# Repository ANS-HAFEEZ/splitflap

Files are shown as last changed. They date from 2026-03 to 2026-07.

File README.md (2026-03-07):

# Split-Flap Display

This is a DIY ESP32-based [split-flap display](https://en.wikipedia.org/wiki/Split-flap_display), optimized for easy assembly at home in small quantities but able to be scaled up to large affordable displays.

animated rendering






The [splitflap community Discord server](https://discord.com/invite/wgehm3PcrC) is the best place to keep up with the latest changes or ask questions about the project!

Want to help support development or just say "thanks"? Consider a one-time or monthly sponsorship:

| [:heart: Sponsor scottbez1 on GitHub](https://github.com/sponsors/scottbez1) |
|---|

<a href="https://www.youtube.com/watch?v=UAQJJAQSg_g" target="_blank">
  
</a>

**Using this project in a commercial setting or for paid client work?** Go right ahead - it's open source (just make sure to follow the terms of the Apache License)! I would, however, ask that you consider [sponsoring the project](https://github.com/sponsors/scottbez1). I've been developing and maintaining this project in my free time for over 10 years, and I'd love to continue working on it. Sponsorships allow me to pay for prototypes and development tools that make this project possible. Unlike pure software projects, every iteration has real hardware costs; sponsorships allow me to keep iterating and improving the project faster. Thank you!

# Current Status
[You can download the **latest stable releases** of the hardware designs from the official 'releases' page.](https://github.com/scottbez1/splitflap/releases)

Releases have been tested and used to produce working units, but as this is a continuously evolving open-source project, there may always be minor issues and/or incomplete documentation from time to time.

Here's a video of a large 108-module display powered by 18 Chainlink Driver boards and a Chainlink Base:

Video: animations on 108-module display (https://youtu.be/g9EPabcxBsM)

## Stable v2 Mechanical Release
As of 2025-01-19, the v2 refresh of the mechanical and sensor design is considered stable and recommended for new builds.

**Here's what's new in v2:**

- **40 flaps per module is the default configuration in this repository**
- **52-flap v2 modules remain supported** if you want additional symbols/color blocks
- **New printed flap design ("Epilogue")** with 52 flaps per set (see animation above), including several color-block flaps
- **Updated enclosure** and mechanical parts (laser-cut) to accomodate both 40- and 52-flap variants
  - Motor wires now exit downward for less awkward wiring!
- **New sensor PCB** that's easier to assemble and includes an LED for checking the magnet status
- **Software-configurable calibration** rather than mechanical sensor adjustment

**But many things are staying the same for easy upgrades/compatibility:**
- No change to flap dimensions!
- No changes to Chainlink Driver, Chainlink Buddy boards, or system architecture!
- 52-flap modules are still an officially supported option!
- Open source, as always!
- v0 parts (sensor kits) will continue to be stocked at Bezek Labs through mid-2025; don't worry if you haven't finished your build yet, the old sensor kits aren't going away for a little while!

I'd love to hear your thoughts and questions about this project, and happy to incorporate any feedback you might have into these designs! Please feel free (and encouraged) to [open GitHub issues](https://github.com/scottbez1/splitflap/issues/new), email me directly, reach out [on Bluesky](https://bsky.app/profile/scottbez1.bsky.social), and [get involved](https://github.com/scottbez1/splitflap/pulls) in the open source development and let's keep chatting and building together!

# Build Your Own
If you have any questions, please don't hesitate to ask in the [community Discord server](https://discord.gg/Hxnftc8PyW)!

* [**Documentation Index**](/docs/DocumentationIndex.md)
* [**Ordering guide (the "easy" route) v2**](/docs/v2/OrderingEasy.md)
* [**Comprehensive ordering guide**](/docs/v2/OrderingComplete.md)
* [**Chainlink Driver Electronics User Guide**](/docs/ElectronicsGuide.md)
* [**Assembly instructions v2**](/docs/v2/Assembly.md)
* [**Latest stable releases**](https://github.com/scottbez1/splitflap/releases)

# Table of Contents
- [Design Overview](#design-overview)
  - [Mechanical](#mechanical)
    - [Combined front panel (script)](#combined-front-panel-script)
    - [Flap font/sticker generator (script)](#flap-fontsticker-generator-script)
  - [Electronics](#electronics)
    - [Sensor PCBs](#sensor-pcbs-1-per-module)
    - [Chainlink Driver](#chainlink-driver-1-per-6-modules)
    - [Chainlink Buddy \[T-Display\]](#chainlink-buddy-t-display-1-for-entire-display)
    - [Advanced items](#advanced-items)
      - [Chainlink Buddy \[Breadboard\]](#chainlink-buddy-breadboard-1-for-entire-display-alternative-to-t-display)
      - [Chainlink Base](#chainlink-base-1-for-entire-display-large-displays)
    - [Older designs](#older-designs)
      - [Classic controller](#classic-controller-electronics-deprecated)
    + [Miscellaneous Tools](#miscellaneous-tools)
      - [3D Printed Tools](#3d-printed-tools)
      - [Chainlink Driver Tester](#chainlink-driver-tester)
  * [Code](#code)
    + [Firmware](#firmware)
    + [Computer Control Software](#computer-control-software)
- [Contributing/Modifying](#contributingmodifying)
  * [3D Design](#3d-design)
  * [Electronics Design](#electronics-design)

# Design Overview

## Mechanical
The mechanical/structural components are made from laser-cut 3mm MDF or acrylic, and held together with M4 bolts and nuts. The design is parametric and built using OpenSCAD. See below for more info on rendering/modifying the design.

You can view an interactive 3d model of the design [here](https://scottbez1.github.io/splitflap/embed.html?branch=master).

The v2 mechanical design officially supports both 40- and 52-flap variants (52 is perfect for use with the new ["Epilogue" printed flaps](https://bezeklabs.etsy.com/listing/1685633114/)). Repository defaults are configured for 40 flaps, but you can always override this.

### v2 (52-flap module option)
2d laser cut rendering

Instructions: [v2 assembly guide](/docs/v2/Assembly.md)

Module dimensions: 

Latest auto-generated (untested!) artifacts<sup>:warning:</sup>:
* For Ponoko 3mm MDF ([svg](https://s3.amazonaws.com/splitflap-artifacts/master/3d/3d_laser_vector-52-ponoko-3mm-mdf_1x.svg)) 
* For Ponoko 3mm acrylic ([svg](https://s3.amazonaws.com/splitflap-artifacts/master/3d/3d_laser_vector-52-ponoko-3mm-acrylic_1x.svg)) 
* For generic material (0.18mm kerf correction) ([svg](https://s3.amazonaws.com/splitflap-artifacts/master/3d/3d_laser_vector-52.svg))
* For Elecrow 3mm Wood ([zipped pdf](https://s3.amazonaws.com/splitflap-artifacts/master/3d/3d_laser_vector-52-elecrow-3mm-wood_1x.zip))
* For Elecrow 3mm Acrylic ([zipped pdf](https://s3.amazonaws.com/splitflap-artifacts/master/3d/3d_laser_vector-52-elecrow-3mm-acrylic_1x.zip))

<sup>:warning:</sup>For tested/stable/recommended artifacts, always use the [latest release](https://github.com/scottbez1/splitflap/releases) instead, as the links on this page will change over time.

### v2 (40-flap module option - default)
2d laser cut rendering

Instructions: [v2 assembly guide](/docs/v2/Assembly.md)

Module dimensions: 

Latest auto-generated (untested!) artifacts<sup>:warning:</sup>:
* For Ponoko 3mm MDF ([svg](https://s3.amazonaws.com/splitflap-artifacts/master/3d/3d_laser_vector-40-ponoko-3mm-mdf_1x.svg)) 
* For Ponoko 3mm acrylic ([svg](https://s3.amazonaws.com/splitflap-artifacts/master/3d/3d_laser_vector-40-ponoko-3mm-acrylic_1x.svg)) 
* For generic material (0.18mm kerf correction) ([svg](https://s3.amazonaws.com/splitflap-artifacts/master/3d/3d_laser_vector-40.svg))
* For Elecrow 3mm Wood ([zipped pdf](https://s3.amazonaws.com/splitflap-artifacts/master/3d/3d_laser_vector-40-elecrow-3mm-wood_1x.zip))
* For Elecrow 3mm Acrylic ([zipped pdf](https://s3.amazonaws.com/splitflap-artifacts/master/3d/3d_laser_vector-40-elecrow-3mm-acrylic_1x.zip))

<sup>:warning:</sup>For tested/stable/recommended artifacts, always use the [latest release](https://github.com/scottbez1/splitflap/releases) instead, as the links on this page will change over time.

### Combined front panel (script)
By default, the design will have a separate laser-cut faceplate for each individual module. For larger displays you may want to combine front panels into a single piece, and the repo has a script to help with this.

You can modify:
* Number of rows and columns
* Horizontal and vertical spacing/separation of modules
* Overall outer width and height of the panel

There are a lot of options; see the `--help` for explanations.

#### Example 1 - Laser cut 6x1

<a href="https://s3.amazonaws.com/splitflap-artifacts/master/3d/3d_front_panel-40-elecrow-3mm-acrylic-6x1.svg">

</a>

```
python3 3d/scripts/generate_combined_front_panel.py \
  --kerf-preset elecrow-3mm-acrylic \
  --num-flaps 40 \
  --cols 6 \
  --rows 1 \
  --spacing-x 0 \
  --spacing-y 0 \
  --frame-margin-x 0 \
  --frame-margin-y 0 \
  --center-mode module
```

#### Example 2 - CNC router 12x2, with frame margin
<a href="https://s3.amazonaws.com/splitflap-artifacts/master/3d/3d_front_panel-40-3.175-20x4margin-12x2.svg">

</a>

For CNC cutting, the script supports rendering a vector file optimized for thicker material (e.g. 6mm MDF) where only the bolt-holes will be through-cut. In this mode, the slots for the top/bottom enclosure pieces can be cut as ~4mm pockets so they aren't visible from the front face. The script automatically generates dog-bone shapes for these pocket cuts.

This example also demonstrates use of the --frame-margin-x and --frame-margin-y options to add an additional margin of 20mm horizontally and 4mm vertically to the front panel dimensions.

```
python3 3d/scripts/generate_combined_front_panel.py \
  --tool-diameter 3.175 \
  --num-flaps 40 \
  --cols 12 \
  --rows 2 \
  --spacing-x 0 \
  --spacing-y 0 \
  --frame-margin-x 20 \
  --frame-margin-y 4 \
  --center-mode module
```

### Flap font/sticker generator (script)
If you'd like to print your own flaps, or cut custom vinyl letter stickers, the project includes a script (`generate_fonts.py`) to generate vector design files, which is extremely configurable:

* Font for text
  * This is further customizable in `flap_fonts.scad` -- this is where font parameters are defined like the overall font scale, position offsets, and even per-character scale and position overrides in case you need to tweak particularly problematic letters (e.g. a really wide "W" or an "@" with too thin of a stroke).
* Character-set - which letters/numbers/symbols/colors are included and in what order
* Bleed - extends rendering past the borders of the flaps to compensate for slight misalignment of printing and cutting operations
* Keepout areas - option to highlight keepout violations for manual review, automatically clip them, or ignore them
* Rendering options:
    * Single-sided - useful for previewing how all letters will look on flaps
    * Front/back - for batch duplex printing, generate separate front-side and back-side files (e.g. sign shop printing on a flat sheet of PVC)
    * Side-by-side - for individual flap printing, each flap's front design is laid out side-by-side with its back design

There are a lot of options; see the `--help` for explanations.

#### Example 1 - Epilogue font, rendered in front+back pairs, default character set, 1mm bleed (for printing)

<a href="https://s3.amazonaws.com/splitflap-artifacts/master/3d/font_example-Epilogue-1mmBleed.svg">

</a>

```
python3 3d/scripts/generate_fonts.py \
  --mode side-by-side \
  --font Epilogue \
  --columns 4 \
  --bleed 1 \
  --fill
```

## Electronics
> [!NOTE]
> For small displays (up to 3 modules), you can skip the custom controller boards and use off-the-shelf ULN2003A driver
modules plugged into an Arduino Uno. This is [partially documented in the wiki](https://github.com/scottbez1/splitflap/wiki/Electronics#basic-prototyping-alternative-electronics-approach)
> but may require some additional tinkering to get it to work. _Help wanted: if you'd like to help improve these instructions,
> please reach out in the Discord server, thanks!_

The "Chainlink" electronics system is designed to support long chains of driver boards to control medium/large displays (up to 100+ split-flap modules).
It's also designed to be easy and cheap to order pre-assembled or build yourself, especially in higher
quantities, due to its simple BOM and surface-mount components.

To build a display, you'll need 3 different electronics:
* One **Sensor PCB** for every split-flap module
* One **Chainlink Driver** board for every 6 split-flap modules. This is what interfaces with the motors and sensors of each module. Chainlink Driver boards can be chained together to construct a large display.
* An ESP32 microcontroller board. There are a few options:
    * For small/medium displays, one of the **Chainlink Buddy** boards are recommended
        * **Chainlink Buddy [T-Display]**  holds a Lilygo T-Display ESP32 module which includes a built-in LCD and 2 buttons
        * **Chainlink Buddy [Breadboard]** makes it easy to connect a Chainlink Driver to a breadboard for prototyping, though you can also easily connect a Chainlink Driver to a breadboard with a few dupont wires.
    * For large displays, the **Chainlink Base** provides a number of advanced features: central
power management/distribution and fault monitoring, UART and RS-485 connections, configuration switches, and status LEDs.

### Sensor PCBs (1 per module)
Each module needs a hall-effect sensor for start-up calibration and fault monitoring. 

#### Sensors v2

<a href="https://s3.amazonaws.com/splitflap-artifacts/master/electronics-v2/panelized_sensor_smd-front-3d.png">

</a>
<a href="https://s3.amazonaws.com/splitflap-artifacts/master/electronics-v2/panelized_sensor_smd-back-3d.png">

</a>

<a href="https://s3.amazonaws.com/splitflap-artifacts/master/electronics-v2/sensor_smd-schematic.pdf">

</a>

New sensors for the v2 laser-cut hardware - these use surface mount components and are optimized for PCB assembly at JLCPCB. These new sensors are not compatible with v0.7 and older laser-cut hardware.

Packs of 6 sensors are [available mostly-assembled in the Bezek Labs store](https://bezeklabs.etsy.com/listing/1696745674),
and come with the right-angle pin headers and magnets you'll need. Purchases support continued development of this project.

Latest auto-generated (untested!) artifacts<sup>:warning:</sup>:

* Schematic [pdf](https://s3.amazonaws.com/splitflap-artifacts/master/electronics-v2/sensor_smd-schematic.pdf)
* Interactive BOM (for manual assembly) [interactive](https://s3.amazonaws.com/splitflap-artifacts/master/electronics-v2/sensor_smd-ibom.html)
* Fabrication files (single)
  * NOTE: PCBs must be 0.8mm! (rather than the more typical 1.6mm thickness)
  * PCB gerbers [zip](https://s3.amazonaws.com/splitflap-artifacts/master/electronics-v2/sensor_smd-jlc/gerbers.zip)
  * PCB BOM (for JLCPCB assembly) [csv](https://s3.amazonaws.com/splitflap-artifacts/master/electronics-v2/sensor_smd-jlc/bom.csv)
  * PCB CPL (for JLCPCB assembly) [csv](https://s3.amazonaws.com/splitflap-artifacts/master/electronics-v2/sensor_smd-jlc/pos.csv)
* Fabrication files (panelized)
  * NOTE: PCBs must be 0.8mm! (rather than the more typical 1.6mm thickness)
  * PCB gerbers [zip](https://s3.amazonaws.com/splitflap-artifacts/master/electronics-v2/sensor_smd-panelized-jlc/gerbers.zip)
  * PCB BOM (for JLCPCB assembly) [csv](https://s3.amazonaws.com/splitflap-artifacts/master/electronics-v2/sensor_smd-panelized-jlc/bom.csv)
  * PCB CPL (for JLCPCB assembly) [csv](https://s3.amazonaws.com/splitflap-artifacts/master/electronics-v2/sensor_smd-panelized-jlc/pos.csv)
* Purchase sensor kits in the US: [Bezek Labs](https://bezeklabs.etsy.com/listing/1696745674)

<sup>:warning:</sup>For tested/stable/recommended artifacts, always use the [latest release](https://github.com/scottbez1/splitflap/releases) instead, as the links on this page will change over time.

### Chainlink Driver (1 per 6 modules)
<a href="https://s3.amazonaws.com/splitflap-artifacts/master/electronics-chainlink/chainlinkDriver-3d.png">

</a>

Key features:
* Controls 6 split-flap modules per board
* Primarily SMD and all components (except the pin headers and motor connectors) are available in JLCPCB's parts library
for easy SMD/THT assembly
* Clock and latch lines are buffered on each board with a 74HC125 to support longer chains
* 2 bits of loopback error checking per board (connecting 2 spare output bits on output shift registers to 2 spare inputs) allows the controller
to validate data integrity up and down the whole chain
* Module order goes from right-to-left since this is intended to be installed and accessed from *behind* the modules

Chainlink Driver boards are [available mostly-assembled in the Bezek Labs store](https://bezeklabs.etsy.com/listing/1123280069/splitflap-chainlink-driver-v11),
and come with the additional connectors and ribbon cables you'll need. Purchases support continued development of this project.

More information on building and using Chainlink Drivers is available in the [Chainlink Driver User Guide](/docs/ElectronicsGuide.md).

Or if you'd like to order these directly from a fab, this design is optimized for assembly at JLCPCB, and files are automatically generated
for ordering *assembled* PCBs there. Or if you wish to assemble this board yourself instead of paying for assembly, 
you can view the [interactive BOM/placement tool](https://s3.amazonaws.com/splitflap-artifacts/master/electronics-chainlink/bom/chainlinkDriver-ibom.html)

Depending on available stock at JLCPCB, you may need to manually modify the BOM file to use alternative components, or regenerate the files
yourself using `export_jlcpcb.py` and specifying one or more `LCSC_ALT_*` field names to use a pre-selected alternative part number. See
the schematic for available pre-selected alternatives (check the symbol's properties/fields).

<a href="https://s3.amazonaws.com/splitflap-artifacts/master/electronics-chainlink/chainlinkDriver-schematic.pdf">

</a>

<a href="https://s3.amazonaws.com/splitflap-artifacts/master/electronics-chainlink/chainlinkDriver-pcb-raster.png">

</a>

Latest auto-generated (untested!) artifacts<sup>:warning:</sup>:

* Schematic [pdf](https://s3.amazonaws.com/splitflap-artifacts/master/electronics-chainlink/chainlinkDriver-schematic.pdf)
* PCB overview [pdf](https://s3.amazonaws.com/splitflap-artifacts/master/electronics-chainlink/chainlinkDriver-pcb-packet.pdf)
* PCB gerbers [zip](https://s3.amazonaws.com/splitflap-artifacts/master/electronics-chainlink/chainlinkDriver-jlc/gerbers.zip)
* PCB bom (for JLCPCB assembly) [csv](https://s3.amazonaws.com/splitflap-artifacts/master/electronics-chainlink/chainlinkDriver-jlc/bom.csv)
* PCB CPL (for JLCPCB assembly) [csv](https://s3.amazonaws.com/splitflap-artifacts/master/electronics-chainlink/chainlinkDriver-jlc/pos.csv)
* PCB bom (for manual assembly) [interactive](https://s3.amazonaws.com/splitflap-artifacts/master/electronics-chainlink/bom/chainlinkDriver-ibom.html)

<sup>:warning:</sup>For tested/stable/recommended artifacts, always use the [latest release](https://github.com/scottbez1/splitflap/releases) instead, as the links on this page will change over time.

### Chainlink Buddy \[T-Display\] (1 for entire display)
<a href="https://s3.amazonaws.com/splitflap-artifacts/master/electronics-chainlink-buddy-t-display/chainlinkBuddyTDisplay-3d.png">

</a>

The Chainlink Buddy \[T-Display\] is a convenient way to connect a T-Display ESP32 board (recommended microcontroller) to a chain
of Chainlink Drivers.

Key features:
* TTGO T-Display ESP32 module as the controller, which includes USB-C, color IPS LCD display and buttons
* Extra terminals for every pin of the T-Display allow you to connect any other peripherals to the ESP32 (the connection to the Chainlink Driver requires _only 4_ of the GPIOs)
* Optional barrel jack makes it easy to use a "wall wart" AC adapter/power-supply (since the Chainlink Driver only has screw terminals for power) -- plug in a 12V supply
and then run a wire from the onboard screw terminals to the Chainlink Driver's motor power screw terminals.
* Optional 5V regulator allows for powering the ESP32 without a USB connection, using the 12V motor power supply

Chainlink Buddy \[T-Display\] boards are [available in the Bezek Labs store](https://bezeklabs.etsy.com/listing/1109357786/splitflap-chainlink-buddy-t-display),
and come with the additional connectors you'll need. Purchases support continued development of this project. 

<a href="https://s3.amazonaws.com/splitflap-artifacts/master/electronics-chainlink-buddy-t-display/chainlinkBuddyTDisplay-schematic.pdf">

</a>

<a href="https://s3.amazonaws.com/splitflap-artifacts/master/electronics-chainlink-buddy-t-display/chainlinkBuddyTDisplay-pcb-raster.png">

</a>

Latest auto-generated (untested!) artifacts<sup>:warning:</sup>:

* Schematic [pdf](https://s3.amazonaws.com/splitflap-artifacts/master/electronics-chainlink-buddy-t-display/chainlinkBuddyTDisplay-schematic.pdf)
* PCB ([gerbers](https://s3.amazonaws.com/splitflap-artifacts/master/electronics-chainlink-buddy-t-display/chainlinkBuddyTDisplay-jlc/gerbers.zip) / [pdf](https://s3.amazonaws.com/splitflap-artifacts/master/electronics-chainlink-buddy-t-display/chainlinkBuddyTDisplay-pcb-packet.pdf))
* Panelized PCB ([gerbers](https://s3.amazonaws.com/splitflap-artifacts/master/electronics-chainlink-buddy-t-display/chainlinkBuddyTDisplay-panelized-jlc/gerbers.zip) / [pdf](https://s3.amazonaws.com/splitflap-artifacts/master/electronics-chainlink-buddy-t-display/chainlinkBuddyTDisplay-panelized-pcb-packet.pdf))
* PCB bom (for manual assembly) [interactive](https://s3.amazonaws.com/splitflap-artifacts/master/electronics-chainlink-buddy-t-display/bom/chainlinkBuddyTDisplay-ibom.html)

<sup>:warning:</sup>For tested/stable/recommended artifacts, always use the [latest release](https://github.com/scottbez1/splitflap/releases) instead, as the links on this page will change over time.

### Advanced items
#### Chainlink Buddy \[Breadboard\] (1 for entire display; alternative to T-Display)
<a href="https://s3.amazonaws.com/splitflap-artifacts/master/electronics-chainlink-buddy-breadboard/chainlinkBuddyBreadboard-3d.png">

</a>

The Chainlink Buddy \[Breadboard\] makes it easy to connect a Chainlink Driver to a breadboard for prototyping. You could use 5 dupont wires and have a
messy rats nest, or you could use a single ribbon cable and this slick breakout board.

Chainlink Buddy \[Breadboard\] boards are [available in the Bezek Labs store](https://bezeklabs.etsy.com/listing/1123863267/splitflap-chainlink-buddy-breadboard),
and come with the additional connectors you'll need. Purchases support continued development of this project. 

<a href="https://s3.amazonaws.com/splitflap-artifacts/master/electronics-chainlink-buddy-breadboard/chainlinkBuddyBreadboard-schematic.pdf">

</a>

<a href="https://s3.amazonaws.com/splitflap-artifacts/master/electronics-chainlink-buddy-breadboard/chainlinkBuddyBreadboard-pcb-raster.png">

</a>

Latest auto-generated (untested!) artifacts<sup>:warning:</sup>:

* Schematic [pdf](https://s3.amazonaws.com/splitflap-artifacts/master/electronics-chainlink-buddy-breadboard/chainlinkBuddyBreadboard-schematic.pdf)
* PCB ([gerbers](https://s3.amazonaws.com/splitflap-artifacts/master/electronics-chainlink-buddy-breadboard/chainlinkBuddyBreadboard-jlc/gerbers.zip) / [pdf](https://s3.amazonaws.com/splitflap-artifacts/master/electronics-chainlink-buddy-breadboard/chainlinkBuddyBreadboard-pcb-packet.pdf))
* Panelized PCB ([gerbers](https://s3.amazonaws.com/splitflap-artifacts/master/electronics-chainlink-buddy-breadboard/chainlinkBuddyBreadboard-panelized-jlc/gerbers.zip) / [pdf](https://s3.amazonaws.com/splitflap-artifacts/master/electronics-chainlink-buddy-breadboard/chainlinkBuddyBreadboard-panelized-pcb-packet.pdf))
* PCB bom (for manual assembly) [interactive](https://s3.amazonaws.com/splitflap-artifacts/master/electronics-chainlink-buddy-breadboard/bom/chainlinkBuddyBreadboard-ibom.html)

<sup>:warning:</sup>For tested/stable/recommended artifacts, always use the [latest release](https://github.com/scottbez1/splitflap/releases) instead, as the links on this page will change over time.

#### Chainlink Base (1 for entire display; large displays)
<a href="https://s3.amazonaws.com/splitflap-artifacts/master/electronics-chainlink-base/chainlinkBase-3d.png">

</a>

For larger displays, you should take additional care to make the hardware more robust to potential faults. The Chainlink Base is an experimental (but unsupported) controller design that adds some additional functionality. This has been tested and appears to work, but is not recommended for general use.

The Chainlink Base PCB is an optional alternative to a Chainlink Buddy, designed for particularly large displays.
It hosts the ESP32 and adds additional connectivity options (terminals for UART and RS485 serial) and
power distribution (independently-monitored power channels for multiple "zones" of Driver boards).

Key features:
* TTGO T-Display ESP32 module as the controller, which includes USB-C, color IPS LCD display and buttons
* Optional master relay output for 12V PSU control (5V relay, up to ~500mA coil current)
  * Future firmware will power on the 12V PSU after a startup self-test, and power off PSU in case of any faults
* 5 channels of independently monitored 12V switches for powering groups of Chainlink Driver boards (6-10A max per channel)
  * Depending on the motors you use, each channel may be able to power about 6 Chainlink Driver boards which is 36 splitflap modules
  * Each channel includes an automotive fuse holder for additional over-current protection
  * INA219 and shunt resistor provide high fidelity voltage and current monitoring 
  * Firmware will power on each channel after a startup self-test, and power off the channel in case of any faults
  * 3.3V output for powering many Chainlink Driver boards
* Flexible controller input power
  * USB power from the T-Display works by default, though external power is recommended for larger displays
  * Regulated 5V can be connected directly to the screw terminals, or
  * if you are using an always-on 12V PSU without a master relay, you can install a buck module and power the board from 12V using the 7-28V screw terminals

<a href="https://s3.amazonaws.com/splitflap-artifacts/master/electronics-chainlink-base/chainlinkBase-schematic.pdf">

</a>

<a href="https://s3.amazonaws.com/splitflap-artifacts/master/electronics-chainlink-base/chainlinkBase-pcb-raster.png">

</a>

Latest auto-generated (untested!) artifacts<sup>:warning:</sup>:

* Schematic [pdf](https://s3.amazonaws.com/splitflap-artifacts/master/electronics-chainlink-base/chainlinkBase-schematic.pdf)
* PCB overview [pdf](https://s3.amazonaws.com/splitflap-artifacts/master/electronics-chainlink-base/chainlinkBase-pcb-packet.pdf)
* PCB gerbers [zip](https://s3.amazonaws.com/splitflap-artifacts/master/electronics-chainlink-base/chainlinkBase-jlc/gerbers.zip)
* PCB bom (for manual assembly) [interactive](https://s3.amazonaws.com/splitflap-artifacts/master/electronics-chainlink-base/bom/chainlinkBase-ibom.html)

<sup>:warning:</sup>There are currently no stable releases of this board, and none are planned. Some past variants of this board have been used, to some success, but it is not considered an
officially supported design

## Older designs
### Classic Controller Electronics (deprecated)
The Classic driver board is deprecated and unsupported.

The Classic controller board was designed to plug into an Arduino like a shield, and could control 4 stepper motors.
Up to 3 driver boards could be chained together, for up to 12 modules controlled by a single Arduino.

The driver uses 2 MIC5842 low-side shift-register drivers, with built-in transient-suppression diodes, to control the motors, and a 74HC165 shift register to read from 4 hall-effect magnetic home position sensors.
There are optional WS2812B RGB LEDs which can be used to indicate the status of each of the 4 channels.

### Miscellaneous Tools

#### 3D Printed Tools
The project also includes a number of optional 3D printed designs to make assembly easier. These include:

* [a flap scoring jig](3d/tools/scoring_jig.scad) for precisely marking the cut point when splitting CR80 cards
* [a flap punch jig](3d/tools/punch_jig.scad) for aligning the punch when making the pin cutouts on either side of a flap
* [a flap container](3d/tools/flap_container.scad) for storing and organizing stacks of completed flaps

All of these designs are parametric and customizable within OpenSCAD. To print them, open up the relevant file in OpenSCAD and use `File -> Export -> Export as STL` to render the design as an STL file for your slicer.

#### Chainlink Driver Tester
<a href="https://s3.amazonaws.com/splitflap-artifacts/master/electronics-chainlink-tester/chainlinkDriverTester-3d.png">

</a>

This is not likely to be useful unless you're planning to manufacture dozens to hundreds of Chainlink Driver boards, but the Chainlink Driver Tester is a complete testbed
for Chainlink Driver boards as they come assembled by the PCBA fabricator.

This is currently under very active development.

Key features:
* TTGO T-Display (ESP32) controller, screen, and buttons for controlling tests and reporting results
* Pogo-pins for all connectors on the Chainlink Driver board-under-test (screw terminals, sensor pin headers, and motor connectors)
* 12V switch to supply motor power to the board-under-test, with automotive fuse and INA219 voltage/current monitoring (based on the Chainlink Base channel switch design)
* Separate 3.3V supply for the board-under-test, protected with a polyfuse, should avoid browning out the Tester's MCU in case of 3.3V short-circuits
* Motor and sensor connections are broken out from the pogo-pins for a full closed-loop hardware test
* Screw terminals to chain another Chainlink Driver (not under test) to validate that chained outputs work on the board-under-test
* MCP23017 GPIO expander with 8 GPIO pins exposed via headers for future expansion inputs
* Large cutout allows a barcode scanner or camera to be aimed at the bottom of the board-under-test for tracking serial numbers.
* Buzzer option for audible pass/fail feedback

<a href="https://s3.amazonaws.com/splitflap-artifacts/master/electronics-chainlink-tester/chainlinkDriverTester-schematic.pdf">

</a>

<a href="https://s3.amazonaws.com/splitflap-artifacts/master/electronics-chainlink-tester/chainlinkDriverTester-pcb-raster.png">

</a>

Latest auto-generated (untested!) artifacts<sup>:warning:</sup>:

* Schematic [pdf](https://s3.amazonaws.com/splitflap-artifacts/master/electronics-chainlink-tester/chainlinkDriverTester-schematic.pdf)
* PCB overview [pdf](https://s3.amazonaws.com/splitflap-artifacts/master/electronics-chainlink-tester/chainlinkDriverTester-pcb-packet.pdf)
* PCB gerbers [zip](https://s3.amazonaws.com/splitflap-artifacts/master/electronics-chainlink-tester/chainlinkDriverTester-jlc/gerbers.zip)
* PCB bom (for manual assembly) [interactive](https://s3.amazonaws.com/splitflap-artifacts/master/electronics-chainlink-tester/bom/chainlinkDriverTester-ibom.html)

<sup>:warning:</sup>There are currently no stable releases of this board, and there may never be as it is a niche production tool, not an end product. If you
need this tool, you are likely actively involved in development and should understand the revision history and current status of development enough to make
an informed decision about which revision(s) to use.

## Code
### Firmware
The driver firmware is written using PlatformIO with the Arduino framework and is available at [`firmware/`](firmware/). 

The firmware implements a closed-loop controller that accepts letters as input over USB serial and drives the stepper motors using a precomputed acceleration ramp for smooth control. The firmware automatically calibrates the spool position at startup, using the hall-effect magnetic sensor, and will automatically recalibrate itself if it ever detects that the spool position has gotten out of sync. If a commanded rotation is expected to bring the spool past the "home" position, it will confirm that the sensor is triggered neither too early nor too late; otherwise it will search for the "home" position to get in sync before continuing to the desired letter.

### Serial protocol
In order for a computer to communicate with the splitflap, it appears as a USB serial device.

However, usage of Arduino’s `Serial` is strictly forbidden, and instead a `logger` abstraction is provided for sending basic text debug logs. Other data is transferred in a structured way, described below.

This allows flexibility in the format of data transferred over serial, and in fact the splitflap provides 2 different serial modes that serve different purposes.

#### Plaintext mode

By default, it starts in “plaintext” mode, which is developer-friendly and you’re probably familiar with if you’ve opened a serial monitor with the splitflap connected:
```
{"type":"init", "num_modules":6}
```

However, this isn’t great for programmatically configuring or receiving updates from the splitflap, so instead the firmware offers a programmatic interface using a binary protocol based on Google’s Protobuf standard.

#### Protobuf (binary/programmatic) mode

The protobuf-based binary serial mode is a compact and flexible way to transfer structured data from the host computer to the splitflap and vice-versa.

##### Benefits of protobuf
protobuf provides several benefits over other encoding mechanisms like JSON:

1. Well-defined schema. If you’re curious about the format of data to expect or send, you just need to check the protobuf file
2. Code generation. Instead of hand-writing JSON parsers every time the data changes, protobuf provides code generation of the encoding and decoding logic, and data-structures. Splitflap uses nanopb to generate C structs based off the schema, and all the code for encoding/decoding that data from the binary format.
3. Relatively compact/efficient wire encoding. It’s not a primary goal in this project, but the binary wire encoding is generally fairly compact, due to omitting default/unspecified fields, using variable length encodings, etc. It’s certainly much more compact than JSON which uses strings to describe every field in every message.
4. Backwards/forwards compatibility. Not super relevant to this project, but many common schema changes are backwards and forwards compatible, meaning an older client or a newer client will be able to handle them gracefully.

##### Disadvantages of protobuf

1. Not human-readable. This makes it much harder to debug, as you need something that can interpret messages. Since they’re binary, viewing anything in a terminal directly will be fruitless.
2. Not self-describing. If you come across a JSON document, you can generally tell what it means because fields have string names/labels describing their contents. Protobuf has no such thing (it uses integer field numbers, which does make renaming fields easier) so you need to have a copy of the schema (.proto file - and you’d better hope it matches the data!) in order to understand an encoded message.

This is why the splitflap defaults to plaintext mode to make basic validation/debugging easier.

##### How it works
Protobuf messages are encoded to their binary wire format and a CRC32 checksum appended. Then that entire binary string is COBS encoded into a packet, and delimited/framed by 0 (NULL) bytes when sent over serial. This provides a basic packet-based interface with integrity checks (rather than the raw, stream-based interface of a serial connection).

The splitflap automatically switches to binary protobuf mode when it receives a 0 byte.

### Computer Control Software
The display can be controlled by a computer connected to the ESP32 over USB serial. If you've built a display and want to test it out, check out the web-based demo [here](https://scottbez1.github.io/splitflap) which will connect to your display using USB - no applications/installation necessary!

The firmware supports a plaintext serial mode (enabled by default) for ease of testing, and a protobuf-based binary mode used by the software libraries for enhanced programmatic control and feedback.

You can find example Typescript and Python libraries in the [`software/chainlink`](software/chainlink) folder.

# Contributing/Modifying

Looking to make some modifications or play around with the design on your local machine? Jump right in! Note that all of the scripts and automation are developed for Ubuntu. Mac OS support is planned,
but not currently implemented (but feel free to open a PR if you want to help!).

## 3D Design

The main design file is [`3d/splitflap.scad`](3d/splitflap.scad)

You'll need a recent version of OpenSCAD (e.g. 2015-03), which may need to be installed through the PPA:
`sudo add-apt-repository ppa:openscad/releases`

In general, solid objects such as the enclosure sides or spool components are built from 2d primitives and then extruded to the appropriate thickness for 3d rendering, rather than using 3d primitives. This simplifies the design without losing expressiveness; the perpendicular laser cut beam doesn't allow for cuts that vary in the Z dimension anyway.

Note that while the design is parameterized and many values may be tweaked, there is currently no error checking for invalid parameters or combinations of parameters. Please take care to validate the design if you change any parameters. For instance, while most of the design will adjust to a changed `num_modules` value, certain values may cause some elements to intersect with other elements or protrude beyond their expected dimensions.

### Rendering
#### Laser-cut vector files
The design can be rendered to 2d for laser cutting by running [`3d/scripts/generate_2d.py [--panelize <number>]`](3d/scripts/generate_2d.py), which outputs to `3d/build/laser_parts/combined.svg`. The optional `--panelize` argument allows for rendering a panel of modules in a single SVG, for bulk laser-cutting.

Internally, the design uses a `projection_renderer` module ([`3d/projection_renderer.scad`](3d/projection_renderer.scad)), which takes a list of child elements to render, and depending on the `render_index` renders a single child at a time. It also _adds_ material to each shape to account for the kerf that will be cut away by the laser.

The [`generate_2d.py`](3d/scripts/generate_2d.py) script interacts with the `projection_renderer` module by first using it to determine the number of subcomponents to render, then runs OpenSCAD to export each component to an SVG file. It does some post-processing on the SVG output (notably adds "mm" to the document dimensions), and then combines all components into the single `combined.svg` output.

Once the `combined.svg` file is generated, you'll want to double-check there aren't any redundant cut lines that are shared by multiple adjacent pieces, to save time/cost when cutting. They should be detected automatically (and highlighted in red in the rendering above), but it doesn't hurt to double-check. In Inkscape, select the "Edit paths by nodes" tool and select an edge to delete - the endpoints should turn blue. Then click "Delete segment between two non-endpoint nodes", and repeat this for all other redundant cut lines.

#### Animated gif
The design can be rendered to a rotating 3d animated gif (seen above) by running [`3d/scripts/generate_gif.py`](3d/scripts/generate_gif.py), which outputs to `3d/build/animation/animation.gif`

The `generate_gif.py` script runs multiple OpenSCAD instances in parallel to render the design from 360 degrees to individual png frames, which are then combined into the final gif animation. As part of building the animation, `generate_gif.py` renders the design with multiple configurations (opaque enclosure, see-through enclosure, no-enclosure and no flaps) by setting the `render_enclosure` and `render_flaps` variables.

#### STL models/web viewer
The design can be rendered to a series of STL files (one per color used in the model) in order to be displayed in an [interactive web-based 3d viewer](https://scottbez1.github.io/splitflap/). Similar to the `projection_renderer` used to render individual components for laser-cutting, the [ColoredStlExporter](3d/scripts/colored_stl_exporter.py) detects all the colors used in the model and renders them one-by-one to separate STL files, along with a manifest that maps each STL file to its RGB color. The STL files and manifest are loaded using three.js to display an interactive model on a web site using WebGL. See this blog post for more details on how the export and three.js renderer work: [OpenSCAD Rendering Tricks, Part 3: Web viewer](http://scottbezek.blogspot.com/2016/08/openscad-rendering-tricks-part-3-web.html).

## Electronics Design
All of the electronics are developed using KiCad 5. Panelization is provided by [KiKit](https://github.com/yaqwsx/KiKit) and gerber/BOM generation is provided by [KiBot](https://github.com/INTI-CMNB/KiBot).

### Rendering
The mechanical and electrical design renderings and links above are automatically updated on every commit with the latest rendering. See this blog post for more details on how that works: [Automated KiCad, OpenSCAD rendering using Travis CI](http://scottbezek.blogspot.com/2016/04/automated-kicad-openscad-rendering.html).

The PCB layout can be rendered to an svg or png (seen above) by running [`electronics/scripts/generate_svg.py file.kicad_pcb`](electronics/scripts/generate_svg.py).
This uses KiCad's [Python scripting API](https://docs.kicad-pcb.org/doxygen/md_Documentation_development_pcbnew-plugins.html)
to render several layers to individual svg files, manipulates them to apply color and opacity settings, and then merges them to a single svg.
For additional details, see this blog post: [Scripting KiCad Pcbnew exports](http://scottbezek.blogspot.com/2016/04/scripting-kicad-pcbnew-exports.html).

For reviewing the design, a pdf packet with copper, silkscreen, and drill info can be produced by running [`electronics/scripts/generate_pdf.py file.kicad_pcb`](electronics/scripts/generate_pdf.py).

Gerber files for fabrication can be exported by running [`electronics/scripts/generate_gerber.py file.kicad_pcb`](electronics/scripts/generate_gerber.py).
This generates gerber files and an Excellon drill file with Seeed Studio's [naming conventions](http://support.seeedstudio.com/knowledgebase/articles/1176532-how-to-generate-the-gerber-manufacturing-files) and produces a `.zip` which can be sent for fabrication.

EESchema isn't easily scriptable, so to export the schematic [`electronics/scripts/export_schematic.py`](electronics/scripts/export_schematic.py) starts an X Virtual Frame Buffer (Xvfb) and open the `eeschema` GUI within that virtual display, and then send a series of hardcoded key presses via `xdotool` to interact with the GUI and click through the dialogs. This is very fragile but seems to work ok for now. For additional details, see this blog post: [Using UI automation to export KiCad schematics](http://scottbezek.blogspot.com/2016/04/automated-kicad-schematic-export.html).

# License
I'd love to hear your thoughts and questions about this project, and happy to incorporate any feedback you might have into these designs! Please feel free (and encouraged) to [open GitHub issues](https://github.com/scottbez1/splitflap/issues/new), email me directly, reach out [on Twitter](https://twitter.com/scottbez1), and [get involved](https://github.com/scottbez1/splitflap/pulls) in the open source development and let's keep chatting and building together!

This project is licensed under Apache v2 (see [LICENSE.txt](LICENSE.txt)).

    Copyright 2015-2025 Scott Bezek and the splitflap contributors
    
    Licensed under the Apache License, Version 2.0 (the "License");
    you may not use this file except in compliance with the License.
    You may obtain a copy of the License at
    
        http://www.apache.org/licenses/LICENSE-2.0
    
    Unless required by applicable law or agreed to in writing, software
    distributed under the License is distributed on an "AS IS" BASIS,
    WITHOUT WARRANTIES OR CONDITIONS OF ANY KIND, either express or implied.
    See the License for the specific language governing permissions and
    limitations under the License.

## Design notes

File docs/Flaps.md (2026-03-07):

[<< Back to Documentation Index](../DocumentationIndex.md)

# About flaps
Flap dimensions

The flaps in this design are based around standard credit-card sized PVC cards (aka CR80). Each flap is 1/2 of a card, and has notches cut of the sides to create a "pin" that fits into the flap spool and allows it to flip freely.

Most builds use 40 flaps per module by default in this repository, but 52-flap v2 builds are also supported. For a small 6-character display that will be a total of 240 flaps (40-flap build) or 312 flaps (52-flap build) that need to be cut and have letters applied to them if you take the full DIY approach.

Because there are so many flaps required for larger displays, I've also had custom flaps (both blank and pre-printed) manufactured that I sell in the [Bezek Labs Etsy store](https://bezeklabs.etsy.com/), which can save a lot of time and helps support continued development of this project.

# Option 1: Pre-printed flaps
Bezek Labs professionally cut blank white flaps

If you'd like to save the most time, I sell [packs of profesionally cut and printed flaps](https://www.etsy.com/listing/1685633114), ready to install into your split-flap display. THese are designed for v2 displays.

This is definitely the priciest option since they're completely custom for this project (the pre-printed Epilogue set requires 52 different printed designs), but they look great and will hold up well to long-term use.

Available in <a href="https://www.etsy.com/listing/1685633114">1-packs, 6-packs, and 24-packs in the Bezek Labs Etsy store</a>.

<a href="https://www.etsy.com/listing/1685633114">

</a>

[^ Up to top](#about-flaps)

[<< Back to Documentation Index](../DocumentationIndex.md)

# Option 2: Pre-cut blank flaps
Bezek Labs professionally cut blank white flaps
Bezek Labs professionally cut blank black flaps

An intermediate option is to buy pre-cut blank flaps, and then apply letter stickers of your choice to them. This saves the hassle of cutting/punching every flap, but still involves some tedious work to apply stickers to every flap.

I sell packs of blank flaps in the <a href="https://bezeklabs.etsy.com/listing/979720975">Bezek Labs Etsy store</a>, available in glossy white or matte black.

<a href="https://bezeklabs.etsy.com/listing/979720975">

</a>

You'll need to [apply letter stickers](#33-apply-letter-stickers) to the blank flaps.

[^ Up to top](#about-flaps)

[<< Back to Documentation Index](../DocumentationIndex.md)

# Option 3: DIY flaps
flap with notches cut by hand

If you want the full DIY experience, the flaps can be created by first cutting a CR80 card in half, then punching notches out of each side of the half cards, and finally applying letter stickers to them.

If this sounds tedious, I'll admit that it is, but it's how I built the first few splitflap modules.

## 3.1 Build a flap cutting jig

The notch cut-outs need to be done consistently for all 40 flaps, so we'll first create a jig for the [badge slot punch](http://www.amazon.com/gp/product/B009YDRRB4) to hold a flap in a precise position while cutting it.

The jig can either be created by hand using a PVC card, or, if you have a 3d printer, can simply be printed ([see below](#3d-printing-a-jig))

### 3d printing a jig

If you have a 3d printer, you can print a jig model rather than creating the jig by hand. It will look like this:

3d-printed jig

To print this jig, open [3d/punch_jig.scad](https://github.com/scottbez1/splitflap/blob/master/3d/tools/punch_jig.scad), render it and export to an STL file. You can use your slicer of choice to prepare the model for 3d printing.

3d-rinted jig Model of the 3d printed jig

(Thanks to [@SilentM4X](https://twitter.com/SilentM4X) for the [idea to print the jig](https://twitter.com/SilentM4X/status/974688413373870085)!)

### Creating a jig by hand

The jig created from a PVC card will eventually look like this:

badge punch with alignment jig

To build this, start by taking half a PVC card (or any spare ID or credit card you may have laying around), insert it all the way to the back of the punch, and punch a slot in the center. While the punch is still engaged (holding the card in place), take your X-Acto knife and lightly score the top of the card along the outer edges of the punch (just enough to mark it).

punched card with marked edges

Take the card and a ruler and score it along the 2 lines you marked (cut about 1/3 of the way through the card thickness, but err on the side of cutting less). Then align the ruler with the flat edge of the punched slot nearest the card edge and use the knife to fully cut the card from the right side of the punched slot to the right edge of the card. Then turn the ruler 90 degrees and place it ~1-2mm outside the left side of the punched slot (this determines the thickness of the flap "pin") and cut from the bottom edge of the slot to the top of the card. 

punched card with scores and cuts

Connect those 2 cuts so that the upper right section of the card can be removed entirely:

punched card with section moved

Fold the card 90 degrees away from you along the 2 scored edges:

folded jig

Insert the jig into the punch (the same orientation you originally punched it), and tape it into place:

folded jig in punch folded jig in punch 2

folded jig in punch 3 folded jig in punch 4

Your flap-cutting jig is complete!

[^ Up to top](#about-flaps)

[<< Back to Documentation Index](../DocumentationIndex.md)

## 3.2 Cut flaps

To cut the flaps from CR80 PVC cards, they first need to be cut in half. You could probably do this with a paper guillotine, but I don't own one so I made a jig to score them with a utility knife and then snap them in half.

Start by putting 3 nails into a scrap piece of wood to hold the card in place:

nails to align card

Then, on either side of the working area, place a card or two (I used a PVC card plus a business card) to elevate a ruler which will be clamped in place as a straight edge for scoring.

ruler placement

Make sure the ruler is clamped exactly 1/2 card length away from the two top nails:

ruler alignment

Then slide a blank card under the ruler and hold it tightly against the nails while scoring along the ruler edge.

card to be cut

You should get a nice clean line, which doesn't have to be too deep. 

card with score line

Bend the card away from the cut until it's folded back on itself, making sure that the ends of the card match up with each other (otherwise adjust the ruler alignment to correct for this). Then straighten the card and bend the opposite direction until it snaps in half.

folded card
folded card 2

Do this with 20 cards to get 40 half-cards. Then take each half-card and use the [[flap cutting jig|Build flap cutting jig]] to punch a notch out of each side.

punched card
stack of punched cards

 The punched holes may not be completely clean (e.g. some material left outside the hole) but that's ok. Take some diagonal cutters to clip off the excess material and clean up the top/bottom of the punched notch.

clipping card with diagonal cutters final cut flaps

If you're interested in more precise dimensions for the flaps and cutouts and the reasoning behind those values, see the discussion here: https://github.com/scottbez1/splitflap/issues/8

If you'd like to save yourself some time, an alternative to cutting your own flaps is to purchase pre-cut flaps that I've had professionally made, [available on Etsy](https://bezeklabs.etsy.com/listing/979720975). Purchasing pre-cut flaps from me will also help fund the continued development of this open-source project.

[^ Up to top](#about-flaps)

[<< Back to Documentation Index](../DocumentationIndex.md)

## 3.3 Apply letter stickers

For applying letter stickers to the flaps, I generally recommend purchasing store-bought vinyl letter sticker packs (see the [v2 complete ordering guide](/docs/v2/OrderingComplete.md) or [v0 complete ordering guide](/docs/v0/OrderingComplete.md) for details).

If you have a vinyl cutter like a Cricut or Silhouette, you can use the [generate_fonts.py](https://github.com/scottbez1/splitflap/blob/master/3d/scripts/generate_fonts.py) script to generate a custom flap letter stickers in the font/design of your choice. I recommend following [Dave Madison's excellent blog post](https://www.partsnotincluded.com/building-diy-split-flap-displays/#:~:text=Letter%20Generation) for tips on how to do this! (And kudos to Dave Madison for contributing that font generation script to the project!)

Applying the letter stickers to each of the 40 flaps is a painstaking, slow process. After a bit of practice, it still took me about 1.5 hours and a lot of patience to apply all the stickers to a new set of flaps:

video time-lapse (https://www.youtube.com/watch?v=N_ifOY9FLs8)

**Note:** I've since discovered a better way of applying letter stickers - see [New Instructions](#new-instructions). The [Old Instructions](#old-instructions) are still included below, but no longer recommended.

### New Instructions

Watch the [youtube video](https://www.youtube.com/watch?v=3lFECISLwyI):



This method is a lot less stressful and offers much better alignment than the older method.

1. Tape down old credit cards or hotel keycards so they form a U-shaped jig that cradles 2 flaps. Place 2 blank flaps into that jig. (Optionally tape another card or piece of paper that covers the bottom 3/16 inch (4.76mm) of the bottom flap -- this serves as a baseline for aligning the stickers)
1. Using food storage cling wrap applied tightly over a clear container, place the letter sticker **upside down** (sticky side UP) on the cling wrap. It should be attracted to the cling wrap because of static electricity, which will allow us to flip the whole thing over without the sticker falling off.
1. Flip the container+cling wrap+sticker over, and looking through the clear container and cling wrap, align the letter onto the 2 flaps (using the optional baseline alignment guide mentioned above, if you have it). Press the container down so the sticker adheres to the flaps and remove the container.
1. Using your finger, press down all over the letter sticker to ensure it's adhered and there are no air bubbles.
1. Cut the letter sticker in half along the gap between the 2 flaps.
1. Remove the bottom flap from the jig and set aside. Take the top flap and flip down so it's in the place of the bottom flap, and place a new blank flap in the top position.
1. Repeat steps 2-6 with the next letter sticker.

### Old Instructions

I've found it's easiest to keep the order correct by starting with all but two of the (empty) flaps already on the spool. You can add/remove flaps on the spool by gently squeezing the flap so the middle of the flap bows away from the spool's center: hold your index finger in a cup shape underneath the flap so only the flap's edges touch your finger, and then press your thumb into the center so the flap bends to follow the contour of your index finger. This will cause the pins to move inward enough to slide the flap into or out of place:

Gently bend the flap to add/remove it from the spool

Start with just 2 empty flaps off the spool, flat on your workspace arranged as they would be on the spool (vertically mirroring each other, with the pins in the middle).

For each letter:

1. Use a hobby knife to cut the letter sticker in half. I used a spare PVC card cut to 1.5 inches tall as a guide since it's smaller and easier to move around than a ruler.
1. Peel up half the letter (you can use the knife's blade to help separate the sticker from the backing), and carefully apply it to one of the flaps, with the cut edge along the flap's cut edge.
1. Repeat with the other half of the letter, making sure to align it with the half you already placed.
1. Take the bottom flap and place it back on the spool, in the lower of the two available slots.
1. Take the top flap (still sitting on your workspace) and flip it vertically so it's face-down in the bottom-flap orientation.
1. From the spool, remove the empty flap above the empty slot (above ), and place it on your workspace in the top-flap orientation.
1. Repeat the steps for each letter. You will always be placing the bottom half of the next letter on the back of the flap that has the top half of the previous letter (e.g. the bottom half of "C" is on the back of the flap with the top half of "B", and the bottom half of "9" is on the same physical flap as the top half of "8").

[^ Up to top](#about-flaps)

[<< Back to Documentation Index](../DocumentationIndex.md)

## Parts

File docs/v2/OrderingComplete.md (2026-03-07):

# Splitflap v2 Comprehensive Ordering Guide
[<< Back to Documentation Index](../DocumentationIndex.md)

The instructions below will walk you through ordering all the parts (excluding common tools) needed to build a splitflap v2 display with **6 modules** using the latest Chainlink electronics.

Ready to assemble? Jump ahead to the [Assembly Guide](Assembly.md) 

If you have any questions, please feel free to reach out to me (scott@bezeklabs.com). Or, join the [Discord server](https://discord.gg/wgehm3PcrC), to discuss or ask questions from the wider split-flap community!

😩 Feeling overwhelmed by this document? I don’t blame you, there’s a LOT here… So I put together a much shorter document that favors simplicity over comprehensiveness/lowest-cost,
for people in the US: [+Splitflap Ordering (the “easy” route)](OrderingEasy.md) 

1. [Order laser-cut parts](#order-laser-cut-parts)
3. [Order electronics](#order-electronics)
2. [Order hardware](#order-misc-hardware)

----------
# Order laser-cut parts

There are many places you can get laser-cut parts, but I’ve personally used Ponoko and Elecrow for ordering shipped to the US with an easy online-only process. I’ve previously recommended ordering from Ponoko - and while I still believe they have great quality and customer service so you'll get a great product, they’ve gotten too expensive to be my default recommendation any longer 😞 

For advanced makers: if you want to cut a single front panel that will be shared by an entire row (or grid) of modules, there is a script to do so with lots of configurable options like spacing, rows/cols, and even has a mode for generating geometry for CNC routing with necessary “dog-bones” applied to inside corners — see `generate_combined_front_panel.py`

💡 Note: v2 laser-cut parts are not dimensionally compatible with older v0 modules! If you’re extending an older display, make sure to use the older files (see the v0 [ordering instruction](../v0/OrderingComplete.md))

## Elecrow (recommended)

- Download the appropriate file (40-flap is the default in this repository):
  - 52-flap design (optional)
    - 3mm acrylic
      - Download [zip](https://s3.amazonaws.com/splitflap-artifacts/refs/tags/releases/mechanics/v2/3d/3d_laser_vector-52-elecrow-3mm-acrylic_1x.zip)
      - Go to [Elecrow acrylic laser cutting](https://www.elecrow.com/acrylic-cutting.html) and upload the zip file
      - Enter dimensions: 
      - Select thickness: 3mm
      - Engrave: No
      - Acrylic color: Matte Black (P502) is recommended
    - 3mm wood
      - Download [zip](https://s3.amazonaws.com/splitflap-artifacts/refs/tags/releases/mechanics/v2/3d/3d_laser_vector-52-elecrow-3mm-wood_1x.zip)
      - Go to [Elecrow wood laser cutting](https://www.elecrow.com/5pcs-wood-laser-cutting-service.html)
      - Dimension: 20cm Max * 20cm Max(Thickness: 3mm)
  - 40-flap design (default)
    - 3mm acrylic
      - Download [zip](https://s3.amazonaws.com/splitflap-artifacts/refs/tags/releases/mechanics/v2/3d/3d_laser_vector-40-elecrow-3mm-acrylic_1x.zip)
      - Go to [Elecrow acrylic laser cutting](https://www.elecrow.com/acrylic-cutting.html) and upload the zip file
      - Enter dimensions: 
      - Select thickness: 3mm
      - Engrave: No
      - Acrylic color: Matte Black (P502) is recommended
    - 3mm wood
      - Download [zip](https://s3.amazonaws.com/splitflap-artifacts/refs/tags/releases/mechanics/v2/3d/3d_laser_vector-40-elecrow-3mm-wood_1x.zip)
      - Go to [Elecrow wood laser cutting](https://www.elecrow.com/5pcs-wood-laser-cutting-service.html)
      - Dimension: 20cm Max * 20cm Max(Thickness: 3mm)




## Ponoko (also recommended, but pricey)
- Download the appropriate file (40-flap is the default in this repository)
    - 52-flap design (optional)
        - 3mm Acrylic: [svg](https://s3.amazonaws.com/splitflap-artifacts/refs/tags/releases/mechanics/v2/3d/3d_laser_vector-52-ponoko-3mm-acrylic_1x.svg) 
        - 3mm MDF: [svg](https://s3.amazonaws.com/splitflap-artifacts/refs/tags/releases/mechanics/v2/3d/3d_laser_vector-52-ponoko-3mm-mdf_1x.svg) 
    - 40-flap design (default)
        - 3mm Acrylic: [svg](https://s3.amazonaws.com/splitflap-artifacts/refs/tags/releases/mechanics/v2/3d/3d_laser_vector-40-ponoko-3mm-acrylic_1x.svg) 
        - 3mm MDF: [svg](https://s3.amazonaws.com/splitflap-artifacts/refs/tags/releases/mechanics/v2/3d/3d_laser_vector-40-ponoko-3mm-mdf_1x.svg) 

- Go to [Ponoko](https://www.ponoko.com/) and sign up for an account.
- [Upload](https://www.ponoko.com/designs) the SVG file from above. Confirm the dimensions match the values above, and check that blue lines are set for “Cutting” and black fill is set for “Area Engraving” (or turn this off to skip engraved features)


- Select a material - [MDF](https://www.ponoko.com/materials/mdf-fiberboard) or [Acrylic](https://www.ponoko.com/materials/black-matte-acrylic) are recommended — choose 3.0mm (0.12 inches) thickness. Make sure to check the material’s maximum size against the dimensions provided next to the file links above; some materials may be too small to order the 4x versions.

💡 **Important note if ordering Matte 1-Side acrylic at Ponoko:** you ***must*** immediately send special instructions to Ponoko after placing your order, requesting to have the design engraved on the *glossy* side. This will result in the design being correctly cut so the matte surface will be on the exterior of the display when assembled. From Ponoko support (as of 2021-05-13): 

> The matte is [by default] cut with the matte side up (so engraving happens on this side as well).
> 
> If you would like to place an order and have us engrave on the glossy side, just **reply to the order confirmation page** with your request and we'll be sure to make note in the order details.

----------
# Order electronics

The Chainlink system is a newer electronics system based around the more powerful ESP32 microcontroller (which adds things like wifi support) and incorporates learnings from the earlier Classic Controller. New development is focused on the Chainlink system.

The basic pieces that you’ll need for a Chainlink system:

- **Chainlink Driver board** (1 for every 6 split-flap modules you want to control)
- **Chainlink Buddy** + **ESP32** (1 for the whole display, regardless of size)
- **Sensors** (1 for every split-flap module)

The easiest and best-supported approach is to purchase each of those items from the Bezek Labs Etsy store (US only) - I’ve set up the store so that items comes with the necessary accessories, meaning there are fewer things you need to track down and purchase separately from different suppliers. Proceeds also help fund continued development of the project!

💡 See the [Chainlink User Guide](../ElectronicsGuide.md) for more info about different configurations.

## Order Chainlink Driver


The Chainlink Driver is what drives up to 6 split-flap modules. Multiple Chainlink Drivers can be chained (hence the name!) to create much larger displays (I have created a 108-module display using 18 Chainlink Driver boards).

The Chainlink Driver uses mostly surface-mount components so it’s optimized for factory production moreso than hand-soldering (though you can of course do that if you’d like)

[**Recommended] Option 1: Purchase fully-tested PCBA on Etsy (US shipping only)**
I sell mostly-pre-assembled [Chainlink Driver boards in the Bezek Labs Etsy store](https://bezeklabs.etsy.com/listing/1123280069/splitflap-chainlink-driver-v11) (includes accessories: connectors, ribbon cable)

These have all the tricky surface-mount components already soldered for you. You’ll just need to solder the through-hole connectors, which are pretty easy.

Every single board that I sell goes through a rigorous 100% functionality test which validates every single motor output, sensor input, LED, and data line works as expected, using a custom test jig I developed.

This option also includes all the connectors and ribbon cable you’ll need, so you don’t need to order anything separately!

And, if you want to make sure you get the right 28byj-48 motors instead of just ordering on AliExpress and hoping for the best, I’ve added an option on Etsy to include 6x motors with your Chainlink Driver order! Yes, they’re more expensive than ordering on AliExpress directly, but they’ll ship quickly and you’ll know you’re getting good motors.

**Option 2: Purchase assembled Chainlink Driver from JLCPCB, and purchase connectors and ribbon cable separately**
The Chainlink Driver design is optimized for JLCPCB assembly, so it’s mostly a drag-and-drop process, but you’ll need to carefully understand the options you select. Most importantly, if JLCPCB is out of stock of a component, *they will continue to build your order and simply omit that component!* So be careful to check all warnings or notices that appear when ordering.

Note that JLCPCB assembly involves a number of fixed costs (such as $3 per unique part, and shipping fees) which make larger quantities a better value. 

Download the following 3 items from the latest Chainlink Driver release (v1.1):

- gerber files (for the PCB)
- BOM (specifies which components are needed for assembly)
- CPL (specifies placement locations for components)

To order:



- Go to JLCPCB https://cart.jlcpcb.com/quote
- Upload gerber zip
- Select your quantity, PCB color
- Confirm other parameters:
    - Dimensions: (accept auto-generated dimensions, which will likely be 30.48 x 198.12)
    - PCB Thickness: 1.6
    - Outer Copper Weight: 1oz



- Select SMT Assembly
    - Assemble top side
    - Select your quantity to assemble
    - Tooling holes: select **Added by Customer** (these are included in the design already, so you do not need JLC to add them)
    - Confirm



- Upload BOM File
- Upload CPL (csv) file



- Review parts
    - ⚠️ Make sure you check this step carefully, as any parts that are out of stock will simply be omitted! ⚠️ 
    - “No part selected” is *normal* for several connectors that will not be assembled by JLCPCB (see below) - these will be “J”-prefixed designators such as “Motor A”, “Sensor C”, or “Input” or “Output”

- Review parts placement
- Save to Cart
- Checkout (note that JLC does NOT reserve parts until you’ve checked out and paid your order, so if stock is low there is a chance parts will be missing if you wait to pay!)

If you wish to hand-assemble some of the through-hole connectors rather than having JLCPCB assemble them for you, you can unselect these components when placing your order, then order and assemble them yourself:

- 2x IDC shrouded connectors, 2x4, 2.54mm spacing, e.g. JLC/LCSC [C601937](https://lcsc.com/product-detail/IDC-Connectors_JILN-321008SG0ABK00A01_C601937.html), or on [Digi-Key](https://www.digikey.com/en/products/detail/adam-tech/BHR-08-VUA/9832409)
- 6x JST XH 5 pin connectors, e.g JLC/LCSC [C161872](https://lcsc.com/product-detail/Wire-To-Board-Wire-To-Wire-Connector_JST-Sales-America-B5B-XH-AM-LF-SN_C161872.html). or [C378947](https://lcsc.com/product-detail/Wire-To-Board-Wire-To-Wire-Connector_JST-Sales-America-B5B-XH-A-BK-LF-SN_C378947.html), or LCSC [C157991](https://lcsc.com/product-detail/Wire-To-Board-Wire-To-Wire-Connector_JST-Sales-America-B5B-XH-A-LF-SN_C157991.html), or on [Digi-Key](https://www.digikey.com/en/products/detail/jst-sales-america-inc/B5B-XH-AM-LF-SN/1651037)
- 6x 3-pin male headers, 2.54mm spacing, e.g. JLC/LCSC [C49257](http://), or on Digi-Key [3-pin](https://www.digikey.com/en/products/detail/sullins-connector-solutions/PREC003SAAN-RC/2774851) or purchase [40-pin](https://www.digikey.com/en/products/detail/sullins-connector-solutions/PREC040SAAN-RC/2774814) and break apart, (or readily available in bulk on Amazon, etc)

In order to connect your Chainlink Driver to your microcontroller (or to another Chainlink Driver in a chain), you’ll also need an IDC ribbon cable + connectors:

- 1x 8 conductor 1.27mm spacing ribbon cable (45cm recommended minimum length for chaining), [e.g. on Digi-Key](https://www.digikey.com/en/products/detail/w%C3%BCrth-elektronik/63910815521CAB/8324550)
- 2x IDC cable connectors, e.g. LCSC [C601910](https://lcsc.com/product-detail/IDC-Connectors_JILN-531408YBS0BW01_C601910.html), or on [Digi-Key](https://www.digikey.com/en/products/detail/adam-tech/FCS-08-SG/9832361)
- You could alternatively look for an assembled 8P IDC cable on e.g. Amazon, though make sure it's a straight-through cable (i.e. notches on the connectors both face the same way)

You may get an email from JLCPCB after placing your order, asking to double-check the orientation of the screw terminals. See images below for the correct orientation: the wires would go *over* the Power labels on the PCB to be inserted into the front of the screw terminals.

✅ 3d model of the design with CORRECT screw terminal orientation
✅ Confirmation email from JLCPCB, showing CORRECT screw terminal orientation. If the image they send you looks like this, go ahead and confirm it!
🚫 INCORRECT: If it looks like this, it’s facing the WRONG way!

**Option 3: Purchase bare PCB, components, and hand-assemble**
This is an advanced option which will require hand-soldering surface mount components. While the components aren’t tiny (ICs are SOIC packages and passives are 0603), it will require some skill and patience.

You might also consider ordering a stencil and reflow soldering the components yourself. However, be aware that the PCB is long and thin so it is prone to warping when heated, so you may have difficulty if you plan to use a hot plate rather than an oven.

Follow the instructions from Option 2 above for ordering the PCBs, and instead of selecting assembly, you can use the BOM file to order all the components yourself. The BOM file uses LCSC part numbers.

## Order Chainlink Buddy and ESP32

You’ll connect your ESP32 microcontroller to the first Chainlink Driver in the chain. The best way to do this is with one of the available Chainlink “Buddy” boards, which allow you to plug in the IDC/ribbon cable directly. 

Many different ESP32 modules exist, and most of them should be compatible (as long as they are dual-core), but I strongly recommend the TTGO T-Display (on [Amazon](https://amzn.to/3kHwhMm) for quick shipping [affiliate links help support this project at no cost to you, or use a [non-affiliate link](https://www.amazon.com/LILYGO-T-Display-Arduino-Development-CH9102F/dp/B099MPFJ9M) if you’d prefer], or [AliExpress](http://) if you don’t mind waiting). It includes a 240x135 LCD that the splitflap firmware supports out of the box, which can be very useful for debugging.

**Chainlink Buddy [T-Display]**



The Chainlink Buddy [T-Display] is the recommended approach for most people, and makes it really easy to connect a TTGO T-Display microcontroller to your Chainlink system, with a ribbon cable connector, screw terminals for power, and a barrel jack for convenient 12v power input.

[Recommended] Available [in the Bezek Labs Etsy store (US only)](https://bezeklabs.etsy.com/listing/1109357786/splitflap-chainlink-buddy-t-display) (includes accessories: IDC connector, screw terminals, barrel jack, and female headers).
There’s also an option to include the T-Display ESP32 module as well if you want to make sure you get the right thing.

or, you can order the PCB yourself using the gerbers, and you will also need to order the following items to go with it:

- 1x IDC shrouded connectors, 2x4, 2.54mm spacing, e.g. LCSC [C601937](https://lcsc.com/product-detail/IDC-Connectors_JILN-321008SG0ABK00A01_C601937.html)
- 1x 3-pin 5.08mm spacing screw terminal, e.g. LCSC [C72334](https://lcsc.com/product-detail/Screw-terminal_Ningbo-Kangnex-Elec-WJ500V-5-08-3P_C72334.html)
- 1x 2.1mm barrel jack, e.g. LCSC [C381116](https://lcsc.com/product-detail/AC-DC-Power-Connectors_XKB-Connectivity-DC-005-5A-2-0_C381116.html)
- 2x 12-pin 2.54mm spacing female headers, e.g. LCSC [C350303](https://lcsc.com/product-detail/Female-Headers_HOAUC-2685Y-112CNG1SNA01_C350303.html)

**Chainlink Buddy [Breadboard] (alternative to the T-Display Buddy)**



If you’d like to use a different ESP32 module than the T-Display, the Breadboard Buddy is an alternative to the  simple way to cleanly connect the Chainlink ribbon cable to a breadboard for prototyping. This is not generally recommended, but is available for advanced users.

Available [in the Bezek Labs Etsy Store (US only)](https://bezeklabs.etsy.com/listing/1123863267/splitflap-chainlink-buddy-breadboard) (includes accessories: IDC connector, male pin headers)

or, you can order the PCB yourself using the gerbers and you will also need to order the following items to go with it:

- 1x IDC shrouded connectors, 2x4, 2.54mm spacing, e.g. LCSC [C601937](https://lcsc.com/product-detail/IDC-Connectors_JILN-321008SG0ABK00A01_C601937.html)
- 1x 5-pin 2.54mm spacing male pin headers

## Order Sensors

Each split-flap module will need a hall effect sensor to detect the home position. The best way to mount this is with a small sensor PCB.

[**Recommended] Option 1: Sensor kit v2 on Etsy (US only)**
To keep things simple, this kit includes 6 sets of all the parts you’ll need to assemble sensors:

- 6x Sensor PCB
- 6x 3-pin right angle headers
- 6x 4mm magnet (this will mount onto your spool)
- (optional) 6x sensor cables

https://bezeklabs.etsy.com/listing/1696745674

**Option 2: Order partially-assembled PCBs directly, and order other parts separately**
The v2 sensor design is optimized for JLCPCB assembly, so it’s mostly a drag-and-drop process, but you’ll need to carefully understand the options you select. Most importantly, if JLCPCB is out of stock of a component, *they will continue to build your order and simply omit that component!* So be careful to check all warnings or notices that appear when ordering.

Note that JLCPCB assembly involves a number of fixed costs (such as $3 per unique part, and shipping fees) which make larger quantities a better value.

The sensor PCBs are simple enough that you can easily hand-solder them, so I'd actually recommend Option 3 below (ordering bare PCBs and parts and assembling them yourself) unless you are building a larger display.

To order assembled sensor v2 PCBs, download the following 3 items from the latest v2 sensor release:

- [Panelized gerber files](https://s3.amazonaws.com/splitflap-artifacts/refs/tags/releases/sensor-smd/v2/electronics-v2/sensor_smd-panelized-jlc/gerbers.zip) (for the PCB)
- [Panelized BOM](https://s3.amazonaws.com/splitflap-artifacts/refs/tags/releases/sensor-smd/v2/electronics-v2/sensor_smd-panelized-jlc/bom.csv) (specifies which components are needed for assembly)
- [Panelized CPL](https://s3.amazonaws.com/splitflap-artifacts/refs/tags/releases/sensor-smd/v2/electronics-v2/sensor_smd-panelized-jlc/pos.csv) (specifies placement locations for components)

To order:

- Go to JLCPCB https://cart.jlcpcb.com/quote
- Upload gerber zip
  - Set parameters:
      - Layers: 2
      - Dimensions: (accept auto-generated dimensions)
      - PCB Qty: 5 (remember, the "panel" that you're ordering includes 6x sensors per panel, so the total sensors will be 6x the PCB Quantity you enter here! i.e. you will end up with 30 sensor PCBs with an order of 5 PCBs. You can have fewer than this quantity assembled)
      - Product Type: Industrial/Consumer electronics
  - PCB specifications
      - Different design: 1
      - Delivery format: Panel by Customer
      - Panel Format:
          - Column: 2
          - Row: 3
      - PCB Thickness: 0.8mm ⚠️ This is not the default PCB thickness - make sure to select 0.8mm!
      - PCB Color: green is cheapest considering the less-common 0.8mm thickness
      - LeadFree HASL
  - Other options - leave all of these as defaults<br>

- Select PCB Assembly
    - Note: JLCPCB gives you the choice to only assemble a portion of PCBs you've ordered. In this example, I've shown ordering 5 PCBs (the minimum quantity) and only having 2 of the 5 assembled (the minimum assembly quantity).
    - Assemble top side
    - PCBA Type: Economic
    - PCBA Qty: 2 (This is 2 of the 6x _panels_, for 12x total sensor PCBs. If this option doesn't appear, change PCBA type to Standard then back to Economic!)
    - Tooling holes: Added by JLCPCB
    - Confirm Parts Placement: No (select Yes if you'd like extra assurance and know how to review the production gerber files they provide)
    - Parts Selection: By Customer
    - Advanced Options: leave these all as defaults<br>

- Upload BOM File
- Upload CPL (csv) file
- Make sure to select File provided as: "Complete File, just proceed with my own files"
  Screenshot from 2025-03-04 22-32-38

- Review parts
    - ⚠️ Make sure you check this step carefully, as any parts that are out of stock will simply be omitted! ⚠️
  Screenshot from 2025-03-04 22-33-01

- Review parts placement
  Screenshot from 2025-01-19 23-50-15

- Save to Cart
- Checkout (note that JLC does NOT reserve parts until you’ve checked out and paid your order, so if stock is low there is a chance parts will be missing if you wait to pay!)

You'll also need to purchase these items separately:
- 6x 4mm round magnet (e.g. [Digi-Key](https://www.digikey.com/en/products/detail/radial-magnets-inc/9027/5218822))
- 6x 3-pin right-angle pin headers (e.g. [Digi-Key](https://www.digikey.com/en/products/detail/sullins-connector-solutions/PREC003SBAN-M71RC/2774931))
- 6x 300mm 3-pin “servo” male-to-male cable (e.g. [Amazon](https://amzn.to/3FdxP8K) (10 pack) [or, [non-affiliate link](https://www.amazon.com/VIMVIP-10pcs-300mm-Extension-Futaba/dp/B00N8OX7VO)], or [AliExpress](https://www.aliexpress.com/item/32800106648.html) (10 pack))
https://bezeklabs.etsy.com/listing/966380990/splitflap-sensor-pcb-set-bare

**Option 3: Order bare PCBs directly, and order all parts separately**
Follow the instructions above to order the PCBs but skip the assembly portion.

In addition to the parts mentioned above (magnets, connectors, cables) you’ll also need to order the parts for the PCB itself:
- 6x hall effect sensors (e.g. HX6286, LCSC [C495736](https://www.lcsc.com/product-detail/Hall-Switches_HUAXIN-HX6286ESO_C495736.html?s_z=n_C495736))
- (optional) 6x 0603 red LED (e.g. LCSC [C2286](https://www.lcsc.com/product-detail/LED-Indication-Discrete_Hubei-KENTO-Elec-KT-0603R_C2286.html?s_z=n_C2286))
- (optional for LEDs) 6x 0603 1k resistor (e.g. LCSC [C21190](https://www.lcsc.com/product-detail/Chip-Resistor-Surface-Mount_UNI-ROYAL-Uniroyal-Elec-0603WAF1001T5E_C21190.html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))
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

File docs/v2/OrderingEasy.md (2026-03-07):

# Splitflap v2 Ordering guide
[<< Back to Documentation Index](../DocumentationIndex.md)

This is the “easy” way to order the parts for your splitflap display (United States only). It optimizes for *simplicity in ordering*, not the *lowest possible cost*.

If you’d like to review other options, which could be somewhat cheaper, check out the [full ordering doc](OrderingComplete.md), but if that’s a little overwhelming, you’re in the right place here!

If you have questions, please ask in the [community Discord server](https://discord.gg/Hxnftc8PyW)!

## Laser-cut mechanical parts

**Supplier:** [Elecrow](https://www.elecrow.com/acrylic-cutting.html) has reasonable quality at a decent price

**Material:** Acrylic

The v2 design officially supports either 40 flaps per module or 52 flaps per module. This guide defaults to the 40-flap variant for maximum compatibility, and the advanced ordering instructions cover the 52-flap variant as well.

For reference, the front face of each module is approximately **82.6mm wide** and **143.53mm tall**.

- [ ] Use this file to order a 40-flap design, made of 3mm acrylic (Matte Black (P502) is recommended): [zip](https://s3.amazonaws.com/splitflap-artifacts/refs/tags/releases/mechanics/v2/3d/3d_laser_vector-40-elecrow-3mm-acrylic_1x.zip)
    - Go to [Elecrow acrylic laser cutting](https://www.elecrow.com/acrylic-cutting.html) and upload the zip file
    - Enter dimensions: 
    - Select thickness: 3mm
    - Engrave: No
    - Acrylic color: Matte Black (P502) is recommended

Full ordering instructions, and alternative files for acrylic/mdf or for 52- rather than 40-flap modules can be found [here](OrderingComplete.md).

I’ve previously recommended ordering from Ponoko - and while I still believe they have great quality and customer service, they’ve gotten too expensive to be my default recommendation any longer 😞 

## Electronics

**Supplier:** [Bezek Labs](https://bezeklabs.etsy.com) (yes, I’m biased in recommending my own store, but it really is the easiest purchasing option since these are custom boards and I also include all necessary accessories). 

- [ ] [Chainlink Driver](https://bezeklabs.etsy.com/listing/1123280069/splitflap-chainlink-driver-v11) (1 for every 6 character modules)
    - Ribbon cable length: **45cm**
    - Add motors? **Yes, add 6x 28BYJ-48**
- [ ] [Sensor kit v2 (6x with magnets and headers)](https://bezeklabs.etsy.com/listing/1696745674/splitflap-sensor-kit-v2-beta-6x-with)  (1 for every 6 character modules)
    - Include cables? **YES**
- [ ] [Chainlink Buddy [T-Display]](https://bezeklabs.etsy.com/listing/1109357786/splitflap-chainlink-buddy-t-display) (1 for your *entire* display, up to 36 total character modules)
    - Include ESP32 T-Display Module: **YES**

## Flaps

**Supplier:** [Bezek Labs](https://bezeklabs.etsy.com) (again, I’m biased, but there aren’t any commercial alternatives and making them yourself requires a lot of [time and patience](../Flaps.md#option-3-diy-flaps))

**Two good options** (this tradeoff is totally up to you):

- [ ] [”Epilogue” pre-printed v2 flaps](https://bezeklabs.etsy.com/listing/1685633114/splitflap-epilogue-printed-flaps-beta-52) save a TON of time and look great, but are definitely more expensive. 6-packs and 24-packs are available at a small discount. Only available with white text on a black card.

OR

- [ ] You can buy blank flaps and [apply letter stickers to them yourself](https://www.youtube.com/watch?v=3lFECISLwyI)
    - [ ] [blank flaps](https://bezeklabs.etsy.com/listing/979720975/blank-splitflap-display-flaps) (purchase enough for your module count: 240 for 6x40 modules, or 312 for 6x52 modules)
    - [ ] [vinyl letter stickers](https://amzn.to/37Frsjb) (from Amazon). Blank flaps are available in white or black, and vinyl letter stickers are [available](https://amzn.to/3ieAZj9) in [many](https://amzn.to/37t1y1R) different [colors](https://amzn.to/3tk4Ddh). (1 sticker pack for every **2** modules)

## Hardware

**Supplier:** McMaster-Carr (reliable, but somewhat pricey especially with shipping) or find these common items elsewhere

- [ ] M4 x 10mm **button-head**. 10 bolts needed per module (so you’ll need at least 60x for 6 modules). Must be button-head style (e.g. taller socket-cap bolts will likely cause clearance issues)
    - [McMaster-Carr](https://www.mcmaster.com/92095A190/) pack of 100
- [ ] M4 hex nuts. 10 nuts needed per module (so you’ll need at least 60x for 6 modules)
    - [McMaster-Carr](https://www.mcmaster.com/91828A231/) pack of 100

## Power supply and wiring

**Supplier:** many options, no specific recommendations

For 1-12 modules:

- [ ] 22AWG wire for 3.3v power (gauge is not critical as this is low-current; solid wire is preferable to stranded for use with screw terminals)
- [ ] 12V power supply capable of *at least* **1.5A for every 6 modules**, plus some margin. Searching for “12V CCTV” or LED power supplies is a good way to find supplies that will have the correct barrel jack connector to plug into the Chainlink Buddy [T-Display]. 
    - Assume that the current ratings on supplies sold by Amazon, AliExpress, etc are overstated, so make sure to account for this and select a supply with a higher current rating than needed.
- [ ] 20AWG (or larger diameter, depending on length & number of modules) wire for 12v power and ground

OR, for 13-36 modules:

- [ ] 22AWG wire for 3.3v power (gauge is not critical as this is low-current; solid wire is preferable to stranded for use with screw terminals)
- [ ] 12V power supply capable of *at least* **1.5A for every 6 modules**, plus some margin. *You must connect the power supply to the screw terminals of the first Chainlink Driver* ***directly***. Do not use the Chainlink Buddy’s barrel jack connector with more than 12 modules, as it cannot handle the current requirements!
    - Assume that the current ratings on supplies sold by Amazon, AliExpress, etc are overstated, so make sure to account for this and select a supply with a higher current rating than needed.
- [ ] 16AWG (or larger diameter, depending on length & number of modules) wire for 12v power and ground

OR, more than 36 modules:
> [!WARNING]
> Special considerations apply for displays with more than 36 modules! You must have a strong understanding of the limitations and risks involved with high-current DC power supplies, and should take all reasonable precautions to protect against damage/injury. Make sure to read the Chainlink Driver user guide for more info if you will be building a [large display](../ElectronicsGuide.md#Large-displays) with 36+ modules.

## That’s all!

For instructions on assembly, see the [Splitflap v2 Assembly Guide](Assembly.md) and [Chainlink Driver Electronics User Guide](../ElectronicsGuide.md) 

----------

Link disclosure: As an Amazon Associate I earn from qualifying purchases at no cost to you.

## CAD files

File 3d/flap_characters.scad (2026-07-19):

character_list = " 0123456789";
function get_character_list() = character_list;

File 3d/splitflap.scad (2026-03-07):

/*
   Copyright 2015-2021 Scott Bezek and the splitflap contributors

   Licensed under the Apache License, Version 2.0 (the "License");
   you may not use this file except in compliance with the License.
   You may obtain a copy of the License at

       http://www.apache.org/licenses/LICENSE-2.0

   Unless required by applicable law or agreed to in writing, software
   distributed under the License is distributed on an "AS IS" BASIS,
   WITHOUT WARRANTIES OR CONDITIONS OF ANY KIND, either express or implied.
   See the License for the specific language governing permissions and
   limitations under the License.
*/

use<28byj-48.scad>;
use<assert.scad>;
use<color_util.scad>;
use<flap.scad>;
use<flap_characters.scad>;
use<label.scad>;
use<pcb.scad>;
use<projection_renderer.scad>;
use<rough7380.scad>;
use<spool.scad>;
use<shapes.scad>;

include<flap_dimensions.scad>;
include<global_constants.scad>;
include<m4_dimensions.scad>;

// ##### RENDERING OPTIONS #####

render_3d = true;

// 3d parameters:
render_enclosure = 1; // 0=invisible; 1=translucent; 2=opaque color;
render_flaps = 2; // 0=invisible; 1=front flap only; 2=all flaps
render_flap_area = 0; // 0=invisible; 1=collapsed flap exclusion; 2=collapsed+extended flap exclusion
render_letters = 2;  // 0=invisible; 1=front flap only; 2=all flaps

render_message = "Ag";

render_unit_separation = 0;
render_spool = true;
render_pcb = true;
render_bolts = true;
render_motor = true;

// 2d parameters:
render_index = -1;
render_etch = false;
render_2d_mirror = false;
render_home_indicator_as_cut = false;
render_front_panel = true;

enable_connectors = true;
enable_alignment_bar = true;
enable_mounting_holes = true;
enable_source_info = true;

// Panelization:
panel_vertical = 0;
panel_horizontal = 0;

// Version label:
render_revision = "deadbeef";
render_date = "YYYY-MM-DD";

spool_explosion = 0; // 0-1
spool_strut_explosion = lookup(spool_explosion, [
    [0, 0],
    [0.2, 0],
    [1, 30],
]);
spool_horizontal_explosion = lookup(spool_explosion, [
    [0, 0],
    [1, 8],
]);

num_flaps = 40;
echo(num_flaps=num_flaps);

// Ponoko kerf values are 0.2 mm for MDF and acrylic (all thicknesses)
// Remember: it's better to underestimate (looser fit) than overestimate (no fit)
kerf_width = 0.185;

// MDF, .120in nominal
// https://www.ponoko.com/materials/mdf-fiberboard
thickness = 3.0;

etch_depth = 0.1;  // for render

captive_nut_inset=6;

assembly_inner_radius = m4_hole_diameter/2;


// Rendering Colors
assembly_color = [0.15, 0.15, 0.15];
etch_color = [0.3, 0.3, 0.3];

hardware_color = [0.75, 0.75, 0.8];  // steel, "bfbfcc"
flap_color = [0.05, 0.05, 0.05];
letter_color = color_invert(flap_color);  // inverse of the flap color, for contrast
assembly_colors = [
    color_multiply(assembly_color, [1.161, 1.157, 1.157, 1.0]),
    color_multiply(assembly_color, [0.897, 0.895, 0.895, 1.0]),
    color_multiply(assembly_color, [0.547, 0.542, 0.540, 1.0]),
    color_multiply(assembly_color, [0.268, 0.268, 0.271, 1.0]),
];

bolt_color = hardware_color;
nut_color = color_multiply(hardware_color, [0.933, 0.933, 0.9, 1.0]);  // "b2b2b7" with steel


flap_width_slop = 0.5;  // amount of slop of the flap side to side between the 2 spools

spool_width_slop = 1.4;  // amount of slop for the spool assembly side-to-side inside the enclosure

spool_tab_clearance = 0;  // for the tabs connecting the struts to the spool ends (interference fit)
spool_retaining_clearance = 0.10;  // for the notches in the spool retaining wall
spool_joint_clearance = 0.10;  // for the notched joints on the spool struts


character_list = get_character_list();
echo(character_list=len(character_list));
assert(len(character_list) == num_flaps || _is_projection_rendering, "WARNING: num_flaps and character_list mismatch!");
render_flap_index = undef;
render_string = is_undef(render_flap_index) ? render_message : character_list[render_flap_index];
render_units = len(render_string);

flap_hole_radius = (flap_pin_width + 0.8) / 2;
flap_hole_separation = 1.2;  // additional spacing between hole edges
flap_gap = (flap_hole_radius * 2 - flap_pin_width) + flap_hole_separation;

flap_spool_outset = 0.8;
flap_pitch_radius = flap_spool_pitch_radius(num_flaps, flap_hole_radius, flap_hole_separation); //num_flaps * (flap_hole_radius*2 + flap_hole_separation) / (2*PI);
spool_outer_radius = flap_spool_outer_radius(num_flaps, flap_hole_radius, flap_hole_separation, flap_spool_outset); //flap_pitch_radius + 2*flap_hole_radius;

// Radius where flaps are expected to flap in their *most collapsed* (90 degree) state
exclusion_radius = sqrt(flap_height*flap_height + flap_pitch_radius*flap_pitch_radius);
// Radius where flaps are expected to flap in their *most extended* state
outer_exclusion_radius = flap_pitch_radius + flap_height + 2;

front_forward_offset = flap_pitch_radius + flap_thickness/2;

spool_width = flap_width - flap_notch_depth*2 + flap_width_slop + thickness*2;  // spool width, outside face (spool to spool)
spool_width_clearance = max(spool_width, flap_width + flap_width_slop);  // width clearance for the spool, either for the spool itself or the flaps

//legacyAssert(spool_width >= flap_width, "Flap is wider than spool!");
spool_strut_num_joints = 3;
spool_strut_tab_width=8;
spool_strut_tab_width_narrow=6;
spool_strut_tab_outset=8;
spool_strut_width = (spool_strut_tab_outset + thickness/2) * 2;
spool_strut_length = spool_width;
spool_strut_inner_length = spool_width - 3 * thickness;

spool_strut_exclusion_radius = sqrt((spool_strut_tab_outset+thickness/2)*(spool_strut_tab_outset+thickness/2) + (spool_strut_tab_width/2)*(spool_strut_tab_width/2));

m4_axle_hole_diameter = 4.3;    // Slightly closer fit than the standard m4_hole_diameter, since a loose fit here will cause the spool to sit at a slight angle

magnet_diameter = 4;
magnet_hole_clearance = -0.05;  // interference fit
magnet_hole_radius = (magnet_diameter + magnet_hole_clearance)/2;
magnet_hole_offset = pcb_hole_to_sensor_x();

// Clearance between the motor chassis and the outside right wall of the previous module
28byj48_chassis_height_clearance = 1.4;

motor_shaft_under_radius = 0.08;  // interference fit
motor_slop_radius = 3;


// Width measured from the outside of the walls
enclosure_wall_to_wall_width = thickness + spool_width_slop/2 + spool_width_clearance + spool_width_slop/2 + max(28byj48_mount_bracket_height() + m4_button_head_length, 4 + 28byj48_mount_bracket_height() - spool_width_slop/2) + thickness;

// Width of the front panel
enclosure_width = enclosure_wall_to_wall_width + 28byj48_chassis_height() + 28byj48_chassis_height_clearance - thickness - 28byj48_mount_bracket_height();
front_window_upper_base = (flap_height - flap_pin_width/2);
front_window_overhang = 1;
front_window_upper = front_window_upper_base - front_window_overhang;
front_window_lower = sqrt(outer_exclusion_radius*outer_exclusion_radius - front_forward_offset*front_forward_offset);
front_window_height = front_window_lower+front_window_upper;
front_window_width = spool_width_slop + spool_width_clearance;
front_window_right_inset = thickness;
enclosure_horizontal_inset = (enclosure_width - front_window_width)/2 - front_window_right_inset; // center the window in the front face (the inset is measured with respect to the *outside* of the wall, hence the "front_window_right_inset" correction)
enclosure_vertical_clearance_top = 5; // gap between top of flaps and top of enclosure
enclosure_vertical_clearance_bottom = 1; // gap between bottom of flaps and bottom of enclosure
enclosure_vertical_inset = max(thickness*1.5, m4_nut_width_corners_padded/2); // distance from top of sides to top of the top piece
enclosure_height_upper = exclusion_radius + enclosure_vertical_clearance_top + thickness + enclosure_vertical_inset;
enclosure_height_lower = flap_pitch_radius + flap_height + enclosure_vertical_clearance_bottom + thickness + enclosure_vertical_inset;
enclosure_height = enclosure_height_upper + enclosure_height_lower;

enclosure_horizontal_rear_margin = 2; // minumum distance between the farthest feature and the rear

enclosure_length = front_forward_offset + 28byj48_mount_center_offset() + m4_hole_diameter/2 + enclosure_horizontal_rear_margin;

// distance from the outside spool face to the inside of the left enclosure
pcb_to_spool = enclosure_wall_to_wall_width - front_window_width - thickness + spool_width_slop/2;

// Enclosure tabs: front/back
enclosure_tab_clearance = 0.10;

num_front_tabs = 2;
front_tab_width = (front_window_width) / (num_front_tabs*2 - 1);

enclosure_length_right = front_forward_offset + m4_hole_diameter/2 + enclosure_horizontal_rear_margin;

side_tab_width = 2.5;
side_tab_bolt_head_clearance = m4_button_head_diameter / 2 + 0.5;
side_tab_length = thickness * 0.8;
side_tab_left_inset = 1;

backstop_bolt_vertical_offset = - (exclusion_radius + outer_exclusion_radius)/2;
backstop_bolt_forward_range = 14;
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

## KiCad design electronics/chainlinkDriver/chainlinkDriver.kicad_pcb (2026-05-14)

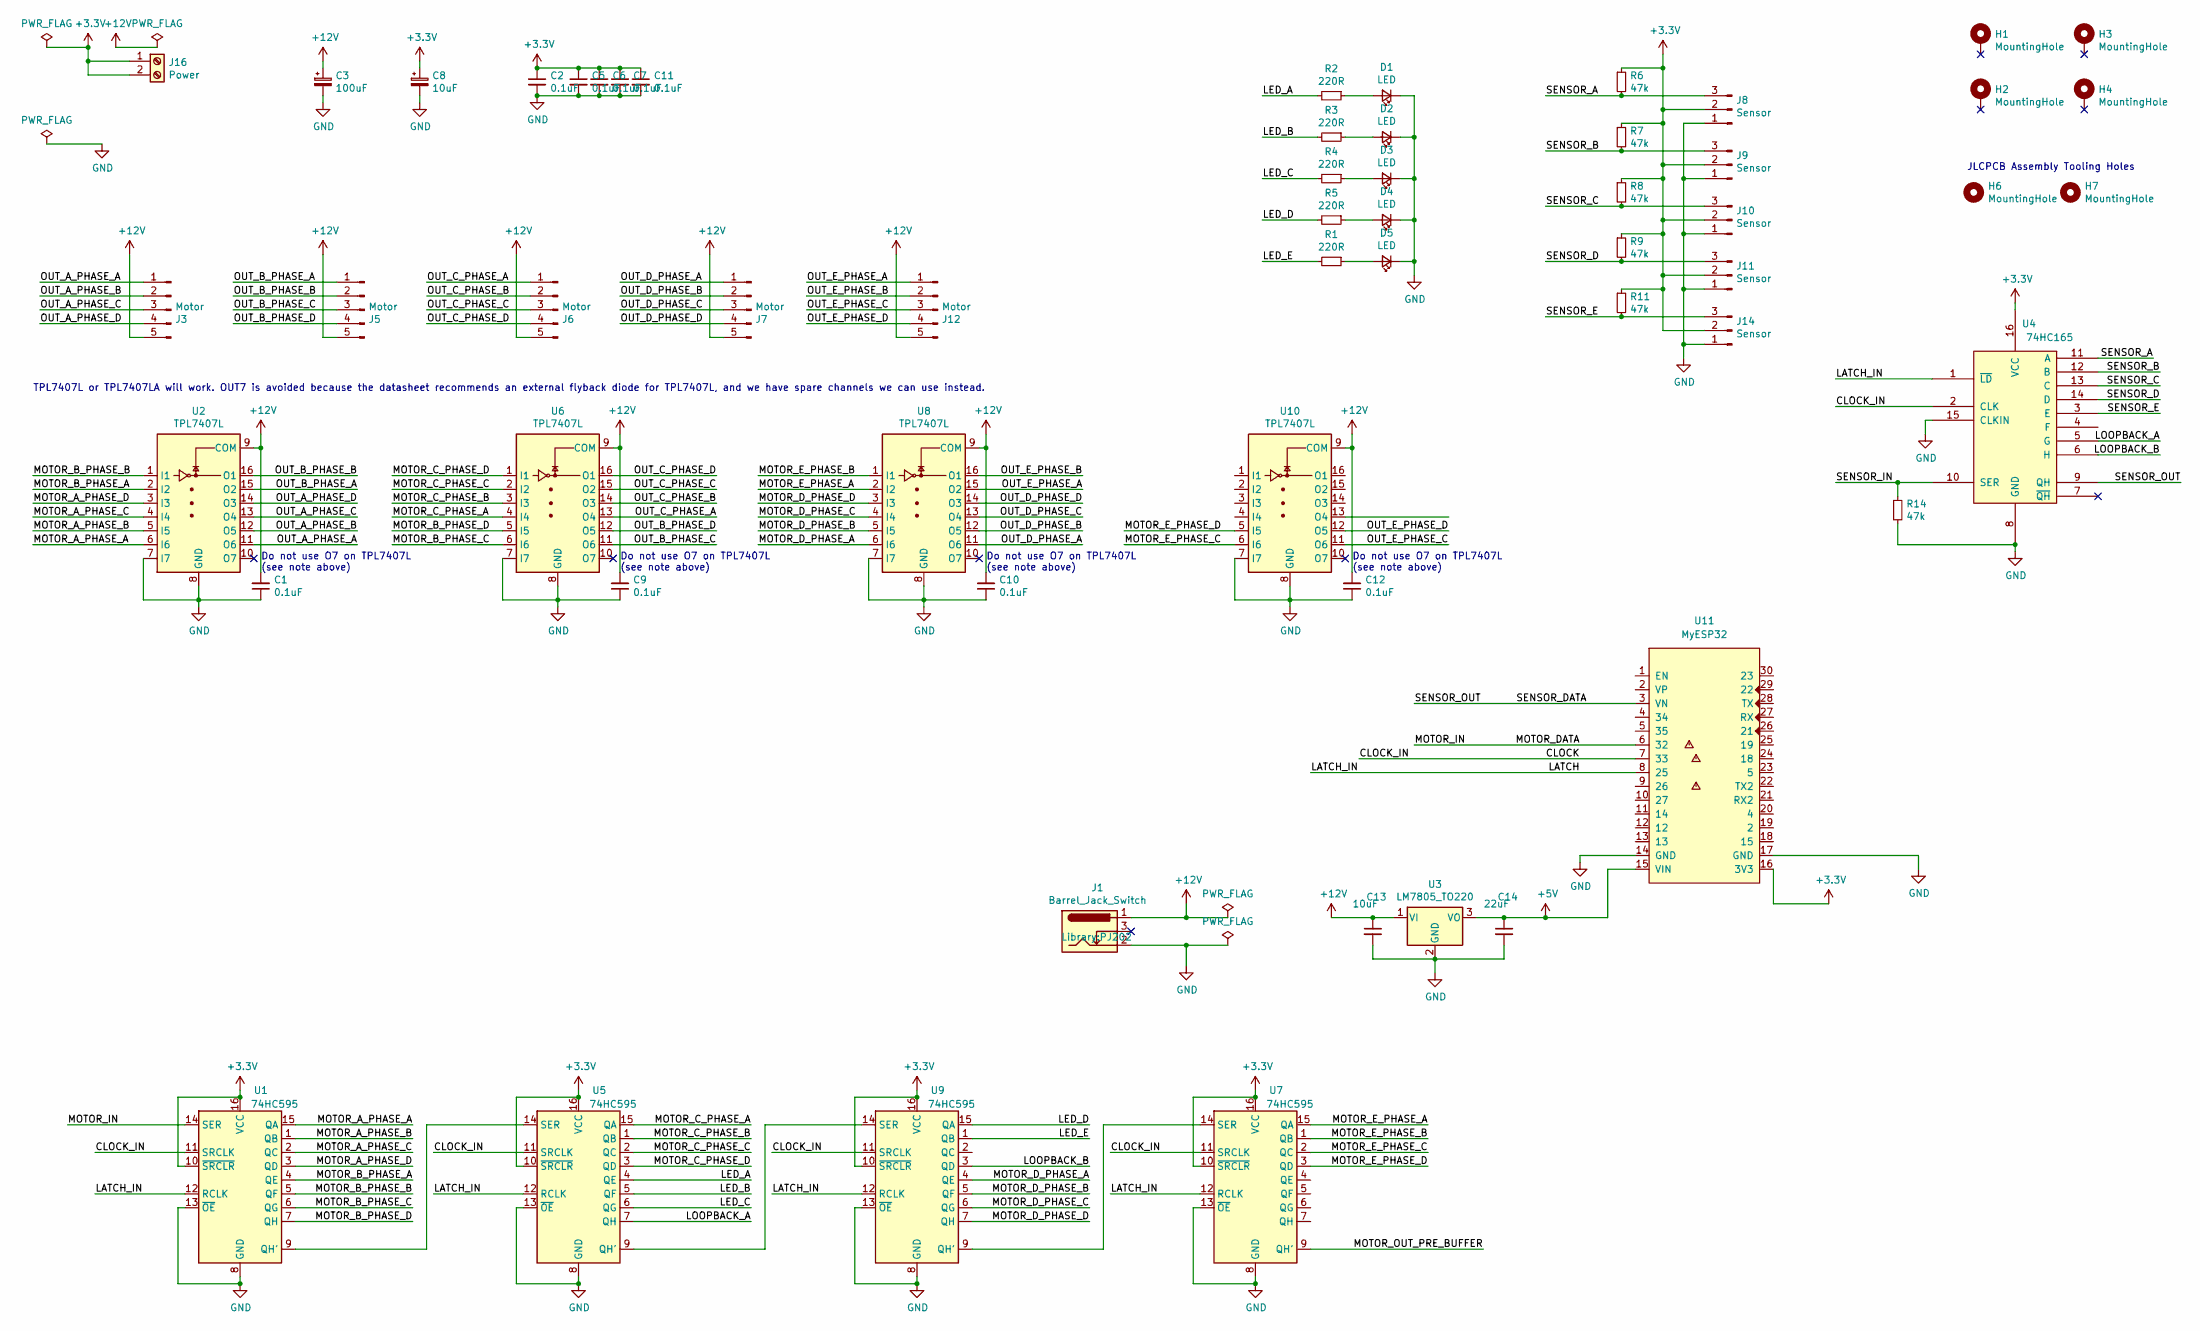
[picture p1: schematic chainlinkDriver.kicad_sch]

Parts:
C1, C2, C5, C6, C7, C9, C10, C11, C12: 0.1uF; C_0603_1608Metric; LCSC C14663
C3: 100uF; CP_Elec_8x10; LCSC C176665
C8: 10uF; CP_Elec_4x5.3; LCSC C176661
C13: 10uF; C_1206_3216Metric_Pad1.33x1.80mm_HandSolder
C14: 22uF; C_1206_3216Metric_Pad1.33x1.80mm_HandSolder
D1, D2, D3, D4, D5: LED; LED_0603_1608Metric_Silkscreen; LCSC C2286
H1, H2, H3, H4: MountingHole; MountingHole_3.2mm_M3_ISO7380_Pad
H6, H7: MountingHole; AssemblyToolingHole
J1: Barrel_Jack_Switch; PJ202
J3, J5, J6, J7, J12: Motor; JST_XH_B5B-XH-A_1x05_P2.50mm_Vertical; LCSC C157991
J8, J9, J10, J11, J14: Sensor; PinHeader_1x03_P2.54mm_Vertical; LCSC C49257
J16: Power; Generic-5.08-2P; LCSC C8465
R1, R2, R3, R4, R5: 220R; R_0603_1608Metric; LCSC C22962
R6, R7, R8, R9, R11, R14: 47k; R_0603_1608Metric; LCSC C25819
U1, U5, U7, U9: 74HC595; SOIC-16_3.9x9.9mm_P1.27mm_silk; LCSC C5947
U2, U6, U8, U10: TPL7407L; SOIC-16_3.9x9.9mm_P1.27mm_silk; LCSC C139663
U3: LM7805_TO220; TO-220-3_Vertical
U4: 74HC165; SOIC-16_3.9x9.9mm_P1.27mm_silk; LCSC C5613
U11: MyESP32

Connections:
+3.3V: C2.1, C5.1, C6.1, C7.1, C8.1, C11.1, J8.2, J9.2, J10.2, J11.2, J14.2, J16.1, J16.2, R6.1, R7.1, R8.1, R9.1, R11.1, U1.10 (~SRCLR), U1.16 (VCC), U4.16 (VCC), U5.10 (~SRCLR), U5.16 (VCC), U7.10 (~SRCLR), U7.16 (VCC), U9.10 (~SRCLR), U9.16 (VCC), U11.16 (3V3)
+5V: C14.1, U3.3 (VO), U11.15 (VIN)
+12V: C1.2, C3.1, C9.2, C10.2, C12.2, C13.1, J1.1, J3.5, J5.5, J6.5, J7.5, J12.5, U2.9 (COM), U3.1 (VI), U6.9 (COM), U8.9 (COM), U10.9 (COM)
/CLOCK: U1.11 (SRCLK), U4.2 (CLK), U5.11 (SRCLK), U7.11 (SRCLK), U9.11 (SRCLK), U11.7 (33)
/LATCH: U1.12 (RCLK), U4.1 (~LD), U5.12 (RCLK), U7.12 (RCLK), U9.12 (RCLK), U11.8 (25)
/LED_A: R2.2, U5.4 (QE)
/LED_B: R3.2, U5.5 (QF)
/LED_C: R4.2, U5.6 (QG)
/LED_D: R5.2, U9.15 (QA)
/LED_E: R1.2, U9.1 (QB)
/LOOPBACK_A: U4.5 (G), U5.7 (QH)
/LOOPBACK_B: U4.6 (H), U9.3 (QD)
/MOTOR_A_PHASE_A: U1.15 (QA), U2.6 (I6)
/MOTOR_A_PHASE_B: U1.1 (QB), U2.5 (I5)
/MOTOR_A_PHASE_C: U1.2 (QC), U2.4 (I4)
/MOTOR_A_PHASE_D: U1.3 (QD), U2.3 (I3)
/MOTOR_B_PHASE_A: U1.4 (QE), U2.2 (I2)
/MOTOR_B_PHASE_B: U1.5 (QF), U2.1 (I1)
/MOTOR_B_PHASE_C: U1.6 (QG), U6.6 (I6)
/MOTOR_B_PHASE_D: U1.7 (QH), U6.5 (I5)
/MOTOR_C_PHASE_A: U5.15 (QA), U6.4 (I4)
/MOTOR_C_PHASE_B: U5.1 (QB), U6.3 (I3)
/MOTOR_C_PHASE_C: U5.2 (QC), U6.2 (I2)
/MOTOR_C_PHASE_D: U5.3 (QD), U6.1 (I1)
/MOTOR_DATA: U1.14 (SER), U11.6 (32)
/MOTOR_D_PHASE_A: U8.6 (I6), U9.4 (QE)
/MOTOR_D_PHASE_B: U8.5 (I5), U9.5 (QF)
/MOTOR_D_PHASE_C: U8.4 (I4), U9.6 (QG)
/MOTOR_D_PHASE_D: U8.3 (I3), U9.7 (QH)
/MOTOR_E_PHASE_A: U7.15 (QA), U8.2 (I2)
/MOTOR_E_PHASE_B: U7.1 (QB), U8.1 (I1)
/MOTOR_E_PHASE_C: U7.2 (QC), U10.6 (I6)
/MOTOR_E_PHASE_D: U7.3 (QD), U10.5 (I5)
/MOTOR_OUT_PRE_BUFFER: U7.9 (QH')
/OUT_A_PHASE_A: J3.1, U2.11 (O6)
/OUT_A_PHASE_B: J3.2, U2.12 (O5)
/OUT_A_PHASE_C: J3.3, U2.13 (O4)
/OUT_A_PHASE_D: J3.4, U2.14 (O3)
/OUT_B_PHASE_A: J5.1, U2.15 (O2)
/OUT_B_PHASE_B: J5.2, U2.16 (O1)
/OUT_B_PHASE_C: J5.3, U6.11 (O6)
/OUT_B_PHASE_D: J5.4, U6.12 (O5)
/OUT_C_PHASE_A: J6.1, U6.13 (O4)
/OUT_C_PHASE_B: J6.2, U6.14 (O3)
/OUT_C_PHASE_C: J6.3, U6.15 (O2)
/OUT_C_PHASE_D: J6.4, U6.16 (O1)
/OUT_D_PHASE_A: J7.1, U8.11 (O6)
/OUT_D_PHASE_B: J7.2, U8.12 (O5)
/OUT_D_PHASE_C: J7.3, U8.13 (O4)
/OUT_D_PHASE_D: J7.4, U8.14 (O3)
/OUT_E_PHASE_A: J12.1, U8.15 (O2)
/OUT_E_PHASE_B: J12.2, U8.16 (O1)
/OUT_E_PHASE_C: J12.3, U10.11 (O6)
/OUT_E_PHASE_D: J12.4, U10.12 (O5)
/SENSOR_A: J8.3, R6.2, U4.11 (A)
/SENSOR_B: J9.3, R7.2, U4.12 (B)
/SENSOR_C: J10.3, R8.2, U4.13 (C)
/SENSOR_D: J11.3, R9.2, U4.14 (D)
/SENSOR_DATA: U4.9 (QH), U11.3 (VN)
/SENSOR_E: J14.3, R11.2, U4.3 (E)
/SENSOR_IN: R14.1, U4.10 (SER)
GND: C1.1, C2.2, C3.2, C5.2, C6.2, C7.2, C8.2, C9.1, C10.1, C11.2, C12.1, C13.2, C14.2, D1.1 (K), D2.1 (K), D3.1 (K), D4.1 (K), D5.1 (K), J1.2, J8.1, J9.1, J10.1, J11.1, J14.1, R14.2, U1.8 (GND), U1.13 (~OE), U2.7 (I7), U2.8 (GND), U3.2 (GND), U4.8 (GND), U4.15 (CLKIN), U5.8 (GND), U5.13 (~OE), U6.7 (I7), U6.8 (GND), U7.8 (GND), U7.13 (~OE), U8.7 (I7), U8.8 (GND), U9.8 (GND), U9.13 (~OE), U10.7 (I7), U10.8 (GND), U11.14 (GND), U11.17 (GND)
unnamed: D1.2 (A), R2.1
unnamed: D2.2 (A), R3.1
unnamed: D3.2 (A), R4.1
unnamed: D4.2 (A), R5.1
unnamed: D5.2 (A), R1.1
unnamed: U1.9 (QH'), U5.14 (SER)
unnamed: U5.9 (QH'), U9.14 (SER)
unnamed: U7.14 (SER), U9.9 (QH')

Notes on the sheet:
Do not use O7 on TPL7407L (see note above)
TPL7407L or TPL7407LA will work. OUT7 is avoided because the datasheet recommends an external flyback diode for TPL7407L, and we have spare channels we can use instead.
JLCPCB Assembly Tooling Holes

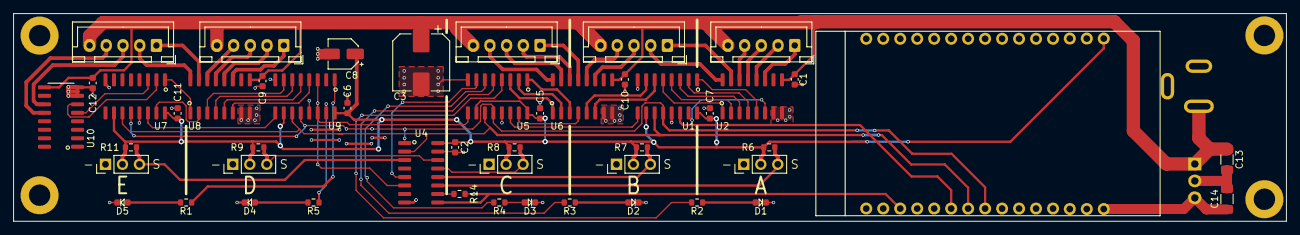
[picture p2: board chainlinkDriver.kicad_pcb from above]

Board: 2 copper layers, 190.4 x 31.1 mm, 55 parts (0 on the bottom side), 69 nets.

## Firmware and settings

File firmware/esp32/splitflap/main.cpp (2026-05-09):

/*
   Copyright 2020 Scott Bezek and the splitflap contributors

   Licensed under the Apache License, Version 2.0 (the "License");
   you may not use this file except in compliance with the License.
   You may obtain a copy of the License at

       http://www.apache.org/licenses/LICENSE-2.0

   Unless required by applicable law or agreed to in writing, software
   distributed under the License is distributed on an "AS IS" BASIS,
   WITHOUT WARRANTIES OR CONDITIONS OF ANY KIND, either express or implied.
   See the License for the specific language governing permissions and
   limitations under the License.
*/

#include <Arduino.h>
#include <TFT_eSPI.h>
#include <Wire.h>

#include "config.h"

#include "../core/configuration.h"
#include "../core/splitflap_task.h"
#include "debug_build_info.h"
#include "display_task.h"
#include "serial_task.h"

Configuration config;

SplitflapTask splitflapTask(1, LedMode::AUTO);
SerialTask serialTask(splitflapTask, 0);

#if ENABLE_DISPLAY
DisplayTask displayTask(splitflapTask, 0);
#endif

#ifdef CHAINLINK_BASE
#include "../base/base_supervisor_task.h"
BaseSupervisorTask baseSupervisorTask(splitflapTask, serialTask, 0);
#endif

#if MQTT
#include "http_server_task.h"
HTTPServerTask httpServerTask(splitflapTask, displayTask, serialTask, 0);
#endif

#if HTTP
#include "http_task.h"
HTTPTask httpTask(splitflapTask, displayTask, serialTask, 0);
#endif

void setup() {
  serialTask.begin();

  config.setLogger(&serialTask);
  bool loaded = config.loadFromDisk();

  splitflapTask.begin();
  splitflapTask.setConfiguration(&config);

  if (loaded) {
    PB_PersistentConfiguration saved = config.get();
    uint16_t offsets[NUM_MODULES] = {};
    for (uint8_t i = 0; i < min(saved.module_offset_steps_count, (pb_size_t)NUM_MODULES); i++) {
      offsets[i] = saved.module_offset_steps[i];
    }
    splitflapTask.restoreAllOffsets(offsets);
  }

  #if ENABLE_DISPLAY
  displayTask.begin();
  #endif

  #if MQTT
  httpServerTask.begin();
  #endif

  #if HTTP
  httpTask.begin();
  #endif

  #ifdef CHAINLINK_BASE
  baseSupervisorTask.begin();
  #endif

  logDebugBuildInfo(serialTask);

  // Delete the default Arduino loopTask to free up Core 1
  vTaskDelete(NULL);
}


void loop() {
  assert(false);
}

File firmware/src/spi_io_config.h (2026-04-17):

/*
   Copyright 2020 Scott Bezek and the splitflap contributors

   Licensed under the Apache License, Version 2.0 (the "License");
   you may not use this file except in compliance with the License.
   You may obtain a copy of the License at

       http://www.apache.org/licenses/LICENSE-2.0

   Unless required by applicable law or agreed to in writing, software
   distributed under the License is distributed on an "AS IS" BASIS,
   WITHOUT WARRANTIES OR CONDITIONS OF ANY KIND, either express or implied.
   See the License for the specific language governing permissions and
   limitations under the License.
*/

#ifndef IO_CONFIG_H
#define IO_CONFIG_H

#include <SPI.h>

#if defined(__AVR_ATmega168__) || defined(__AVR_ATmega328P__)
  #define OUT_LATCH_PIN (4)
  #define _OUT_LATCH_PORT PORTD
  #define _OUT_LATCH_BIT 4

  #define IN_LATCH_PIN (5)
  #define _IN_LATCH_PORT PORTD
  #define _IN_LATCH_BIT 5

  #define OUT_LATCH(){\
    _OUT_LATCH_PORT |= (1 << _OUT_LATCH_BIT);\
    _OUT_LATCH_PORT &= ~(1 << _OUT_LATCH_BIT);\
  }
  #define IN_LATCH() {\
    _IN_LATCH_PORT &= ~(1 << _IN_LATCH_BIT);\
    _IN_LATCH_PORT |= (1 << _IN_LATCH_BIT);\
  }

  #define SPI_CLOCK 3000000

  #define BUFFER_ATTRS
#endif

#ifdef ARDUINO_ESP8266_WEMOS_D1MINI
  #define OUT_LATCH_PIN (D1)
  #define IN_LATCH_PIN (D2)

  #define OUT_LATCH() {digitalWrite(OUT_LATCH_PIN, HIGH); digitalWrite(OUT_LATCH_PIN, LOW);}
  #define IN_LATCH() {digitalWrite(IN_LATCH_PIN, LOW); digitalWrite(IN_LATCH_PIN, HIGH);}

  #define SPI_CLOCK 3000000

  #define BUFFER_ATTRS
#endif

#ifdef ESP32
  #include "driver/spi_master.h"
  #include "driver/spi_slave.h"

  #define LATCH_PIN (25)

  // Optional - uncomment if connecting the output enable pin of the 74HC595 shift registers
  // to the ESP32. You can otherwise hard-wire the output enable pins to always be enabled.
  // #define OUTPUT_ENABLE_PIN (27)

  #define PIN_NUM_MISO 39
  #define PIN_NUM_MOSI 32
  #define PIN_NUM_CLK  33

  // Note: You may need to slow this down to 3MHz if you're using a classic driver board;
  // the MIC5842 only officially supports up to 3.3MHz
  #define SPI_CLOCK 4000000

  #define BUFFER_ATTRS WORD_ALIGNED_ATTR

  // Note: must use HSPI to avoid conflict with ST7789 driver which uses VSPI
  #define SPLITFLAP_SPI_HOST HSPI_HOST
  #define DMA_CHANNEL 1


  spi_device_handle_t spi_tx;
  spi_device_handle_t spi_rx;

  spi_transaction_t tx_transaction;
  spi_transaction_t rx_transaction;


#endif

#if !defined(__AVR_ATmega168__) && !defined(__AVR_ATmega328P__) && !defined(ARDUINO_ESP8266_WEMOS_D1MINI) && !defined(ESP32)
#error "Unknown/unsupported board for SPI mode. ATmega328-based boards (Uno, Duemilanove, Diecimila), ESP8266 and ESP32 are currently supported"
#endif

#ifdef CHAINLINK
#define MOTOR_BUFFER_LENGTH (NUM_DRIVERS * 4)
#define SENSOR_BUFFER_LENGTH (NUM_DRIVERS)
#else
#define MOTOR_BUFFER_LENGTH (NUM_MODULES / 2 + (NUM_MODULES % 2 != 0))
#define SENSOR_BUFFER_LENGTH (NUM_MODULES / 4 + (NUM_MODULES % 4 != 0))
#endif


BUFFER_ATTRS uint8_t motor_buffer[MOTOR_BUFFER_LENGTH];
BUFFER_ATTRS uint8_t sensor_buffer[SENSOR_BUFFER_LENGTH];

#ifdef __AVR__
// Define placement new so we can initialize SplitflapModules at runtime into a static buffer.
// (see https://arduino.stackexchange.com/a/1499)
void* operator new(__attribute__((unused)) size_t size, void* ptr) {
  return ptr;
}
#endif

#ifdef ESP32
void reset_latch(spi_transaction_t *trans) {
    digitalWrite(LATCH_PIN, LOW);
}

void latch_registers(spi_transaction_t *trans) {
    digitalWrite(LATCH_PIN, HIGH);
}
#endif

// Static buffer for SplitflapModules (initialized at runtime)
static char moduleBuffer[NUM_MODULES][sizeof(SplitflapModule)];

SplitflapModule* modules[NUM_MODULES];

#ifdef CHAINLINK
static const uint8_t MOTOR_OFFSET[] = {0, 0, 1, 2, 3, 3};
#endif

inline void initialize_modules() {
  for (uint8_t i = 0; i < NUM_MODULES; i++) {
    // Create SplitflapModules in a statically allocated buffer using placement new
#ifdef CHAINLINK
    modules[i] = new (moduleBuffer[i]) SplitflapModule(motor_buffer[MOTOR_BUFFER_LENGTH - 1 - i/6*4 - MOTOR_OFFSET[i%6]], i % 2 == 0 ? 0 : 4, sensor_buffer[i/6], 1 << (i % 6));
#else
    modules[i] = new (moduleBuffer[i]) SplitflapModule(motor_buffer[MOTOR_BUFFER_LENGTH - 1 - i/2], i % 2 == 0 ? 0 : 4, sensor_buffer[i/4], 1 << (i % 4));
#endif
  }
  
  memset(motor_buffer, 0, MOTOR_BUFFER_LENGTH);
  memset(sensor_buffer, 0, SENSOR_BUFFER_LENGTH);

  // Initialize SPI
#ifdef IN_LATCH_PIN
  pinMode(IN_LATCH_PIN, OUTPUT);
  digitalWrite(IN_LATCH_PIN, HIGH);
#endif

#ifdef OUT_LATCH_PIN
  pinMode(OUT_LATCH_PIN, OUTPUT);
  digitalWrite(OUT_LATCH_PIN, LOW);
#endif

#ifdef LATCH_PIN
  pinMode(LATCH_PIN, OUTPUT);
  digitalWrite(LATCH_PIN, LOW);
#endif
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

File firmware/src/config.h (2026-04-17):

#pragma once

#include <Arduino.h>

/***** CONFIGURATION *****/

// 1) Mode
#define SENSOR_TEST false

// 2) General Settings
#ifndef NUM_MODULES
// Set NUM_MODULES in platformio.ini instead when using ESP32/PlatformIO
#define NUM_MODULES (12)
#endif


// Whether to force a full rotation when the same letter is specified again
#define FORCE_FULL_ROTATION true

// Whether to use/expect a home sensor. Enable for auto-calibration via home
// sensor feedback. Disable for basic open-loop control (useful when first
// testing the split-flap, since home calibration can be tricky to fine tune)
#define HOME_CALIBRATION_ENABLED true

// 3) Flap Contents & Order
// This `flaps` array should match the order of flaps on your spools, with
// the first being the "home" flap.
//
// These are used for the built-in display, plaintext serial interface, and
// can be referenced by interactive controllers using the proto interface, but
// these are non-critical and only useful for interactive usage with the
// standard interfaces. (If you are using custom control software with the
// proto interface - you'll know if you are - you can ignore these since the
// proto interface uses integer indexes to reference flap positions).
//
// The conventions for these are as follows:
// - basic letters should be UPPER CASE
// - lower-case letters can be used to represent color blocks:
//   - g = green
//   - p = purple
//   - r = red
//   - w = white
//   - y = yellow

// Custom flap set: 40 flaps, digits 0-9 counter with remaining blank
#define NUM_FLAPS (40)

// const uint8_t flaps[NUM_FLAPS] = {
//   ' ', '0', '1', '2', '3', '4', '5', '6', '7', '8',
//   '9', ' ', ' ', ' ', ' ', ' ', ' ', ' ', ' ', ' ',
//   ' ', ' ', ' ', ' ', ' ', ' ', ' ', ' ', ' ', ' ',
//   ' ', ' ', ' ', ' ', ' ', ' ', ' ', ' ', ' ', ' ',
// };


const uint8_t flaps[NUM_FLAPS] = {
  '0', ' ', ' ', ' ', '4', ' ', ' ', ' ', '8', ' ',
  ' ', '1', ' ', ' ', ' ', '5', ' ', ' ', ' ', '9',
  ' ', ' ', '2', ' ', ' ', ' ', '6', ' ', ' ', ' ',
  ' ', ' ', ' ', '3', ' ', ' ', ' ', '7', ' ', ' ',
};

// Flap option 2: v2 flaps (52 per module)
// #define NUM_FLAPS (52)
// const uint8_t flaps[NUM_FLAPS] = {
//   ' ', 'A', 'B', 'C', 'D', 'E', 'F', 'G', 'H', 'I', 'J', 'K', 'L',
//   'M', 'N', 'O', 'P', 'Q', 'R', 'S', 'T', 'U', 'V', 'W', 'X', 'Y',
//   'Z', 'g', '0', '1', '2', '3', '4', '5', '6', '7', '8', '9', 'r',
//   '.', '?', '-', '$', '\'', '#', 'y', 'p', ',', '!', '@', '&', 'w'
// };

// Flap option 3: v2 flaps (limited 40-flap set using the first 40 flaps of the set)
// #define NUM_FLAPS (40)
// const uint8_t flaps[NUM_FLAPS] = {
//   ' ', 'A', 'B', 'C', 'D', 'E', 'F', 'G', 'H', 'I', 'J', 'K', 'L',
//   'M', 'N', 'O', 'P', 'Q', 'R', 'S', 'T', 'U', 'V', 'W', 'X', 'Y',
//   'Z', 'g', '0', '1', '2', '3', '4', '5', '6', '7', '8', '9', 'r',
//   '.',
// };

// Flap option 4: YOUR CUSTOM CHARACTER SET HERE!
// #define NUM_FLAPS (40)
// const uint8_t flaps[NUM_FLAPS] = {
//   <FILL THIS IN!>
// };


// 4) Hardware configuration and features
#ifndef SPLITFLAP_PIO_HARDWARE_CONFIG
  // Note: these values are only used in the Arduino IDE. For PlatformIO,
  // hardware configuration is set by the environment, in platformio.ini.
  #define SPI_IO true
  #define REVERSE_MOTOR_DIRECTION false
  #define NEOPIXEL_DEBUGGING_ENABLED true
  #define INA219_POWER_SENSE false
#endif

// 5) Board-dependent Default Settings

#if defined(__AVR_ATmega168__) || defined(__AVR_ATmega328P__)
  #if SPI_IO
  #define NEOPIXEL_PIN 6
  #else
  #define NEOPIXEL_PIN 3
  #endif
  #define MONITOR_SPEED 38400
#elif defined(__AVR_ATmega2560__)
  #define NEOPIXEL_PIN 5
  #define MONITOR_SPEED 38400
#elif defined(ARDUINO_ESP8266_WEMOS_D1MINI)
  #define NEOPIXEL_PIN (D8)
  #define MONITOR_SPEED 38400
#elif defined(ESP32)
  #define NEOPIXEL_PIN (13)
  #define MONITOR_SPEED 230400
#endif

/*************************/
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

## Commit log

2026-04-17 Add KiCad projects and MQTT calibrate feature
2026-04-18 Add decrease-by-1/10 calibration command
2026-04-18 Add Chainlink KiCad schematics and libs
    [chainlinkBuddyTDisplay.kicad_sch, chainlinkDriver.kicad_pcb, chainlinkDriver.kicad_sch]
2026-04-21 Enable Gerber, update PCB routing & local settings
    [chainlinkDriver.kicad_pcb]
2026-05-09 Replace MQTT task with HTTP server task
    [main.cpp]
2026-07-19 Add HTTP calibration tools and fix display ordering
    [flap_characters.scad]
